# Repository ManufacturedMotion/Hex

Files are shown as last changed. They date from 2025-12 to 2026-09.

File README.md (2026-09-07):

# Hex

<a href="https://manufacturedmotion.github.io/Hex/">
  <button>Open Hex Documentation</button>
</a>

Hex is a six legged OpenSource Hexapod designed to serve as a moving platform for you to tinker with and build on top of! 

The current Hexapod release is **Hex3**. Check out our [Hex3 project on Printables!](https://www.printables.com/model/1831798-hex3-an-opensource-hexapod-platform) Hex4 is currently under development, with a target release date in mid- to late- 2027.

Like Tony Stark and his suits, we are continually expanding on the capabilities of the Hexapod platform. Unlike Tony Stark, we hope not to need
85+ different iterations.

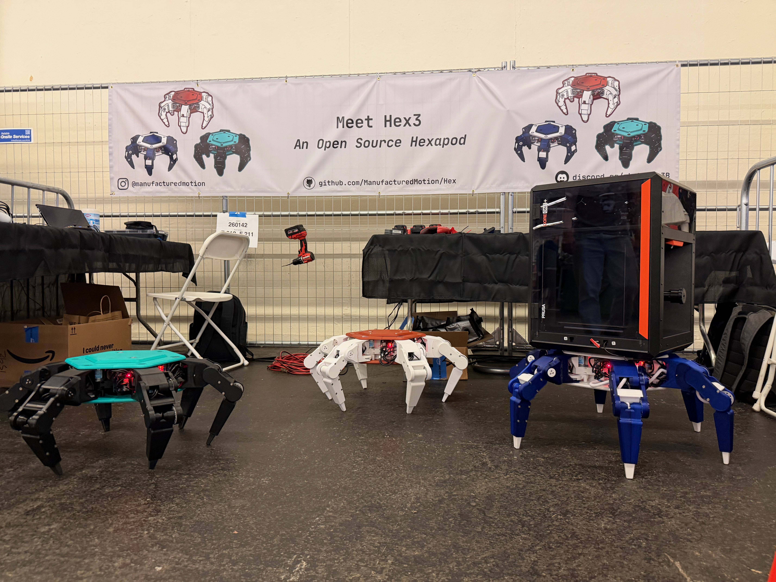
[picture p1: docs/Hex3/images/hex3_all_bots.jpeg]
Hex3 bots at OpenSauce


If you want to build your own or join the community, check out our [Hex Discord](https://discord.gg/v3bbvRtFUr).

To find out info on what we're planning to change, [checkout our GitHub issues!](https://github.com/ManufacturedMotion/Hexapod/issues).

## Generations

### Hex1

- [Overview](https://github.com/ManufacturedMotion/Hexapod/wiki#mk1)
- Completed: July 2023 - May 2024
- MIT LICENSE

### Hex2
- [Overview](https://github.com/ManufacturedMotion/Hexapod/wiki#mk2)
- Completed: May 2024 - July 2025
- MIT LICENSE

### Hex3
- Codename: Dewey
- In-Progress: July 2025 - September 2026
- Code: GNU GENERAL PUBLIC LICENSE V3
- CAD/PCBs: [Open Community License (OCL)](https://github.com/OpenCommunityLicence/OpenCommunityLicence?tab=readme-ov-file#open-community-license-ocl)
- Printables: [Hex3](https://www.printables.com/model/1831798-hex3-an-opensource-hexapod-platform)

### Hex4
- In-Progress: August 2026 - Present

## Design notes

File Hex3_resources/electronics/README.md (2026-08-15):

# Hex3 PCB Electronics

## Overview

This folder contains the Hex3 PCB resources, including the latest leg and main PCB revisions used for this project.

## Leg Board Versions

- `V2.0` - earlier leg board revision.
- `V3.2` - improved leg board revision.

(Both of these boards were used on the hexapods during OpenSauce 2026)

## Key Differences

- `V2.0`:
  - This board added some new features such as:
    - added split termination to our canbus circuit
      - NOTE: our testing showed this feature actually introduced issues. If using the V2.0 design, you will need to cut the traces to remove connection to the split termination circuit. [See our GitHub Pages for HEX3 PCB assembly for detailed instructions](../../docs/Hex3/pcb-assembly.md)
    - added a diode to prevent power issues when connecting to the Xiao via USB
    - 470uF capacitor to stabilize power supply to the Xiao RP2350
    - swaps the polarized DRV capacitors from SMT to through hole for easier assembly
      - for some reason, for the original V1.0 boards, we decided to solder the SMT capacitors by hand instead of having it done by a machine...
    - added TJA1050 chip as we swapped the communication protocol for main PCB <-> leg PCB from I2C to canbus
    - added LTC4311 chip to improve I2C transmission speed and reliability (I2C is still used for encoder reads)

- `V3.2`:
  - This board resolved a few design issues from V2.0, but also is more expensive as we swapped to 2 oz copper pours for all layers
  - Changes from V2.0 include:
    - removed split termination from the canbus circuit
    - added via stitching to the board for better heat dissipation
    - added an option to use header/pogo pins for the Xiao RP2350 connectivity 
    - silk screen changes to 0 index the encoder labels
    - swap the placements of the encoder JST connections, so that S0 is the closest to the top of the board
    - swap the through hole diode for an SMT version

> Please see the [Hex3 PCB assembly documentation](../../docs/Hex3/pcb-assembly.md) for additional notes about assembly and required code changes for either version of the leg board.

## Main Board Versions

- `V2.1`:
  - The main board is more stable than our leg boards, as V2.1 was the only version we used for OpenSauce 2026
  - Our only note is for the addition of a 470uF polarized capactior across the input terminals of one of the buck converters on the board. This is explained on the PCB assembly instructions linked above

## Ordering

PCBs were ordered from JLCPCB, but any PCB vendor that supports ASM should work. Both the main and leg PCBs are designed as 4 layer PCBs

> For convenience and as an example, the BOM and CPL files from our last order have been added only to the `leg_board/` folders.
>> Our order was a bulk order for 25 boards. If using these files as a reference, please adjust the quantities accordingly.

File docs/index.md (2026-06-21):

<p style="text-align:center">
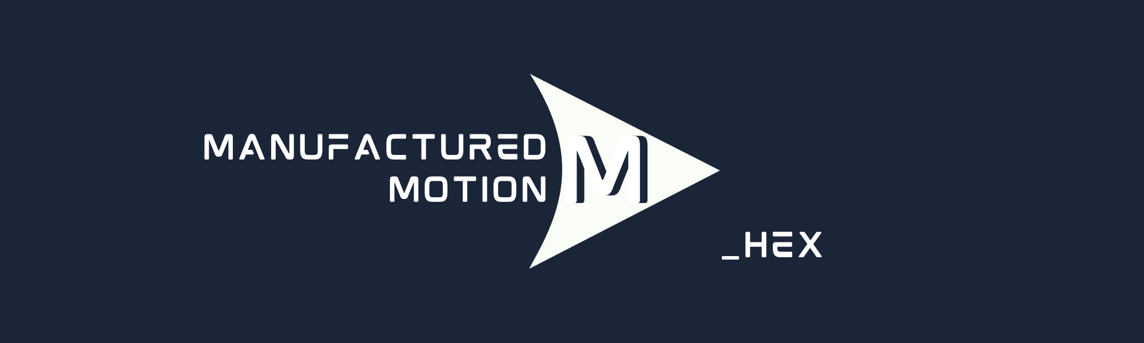
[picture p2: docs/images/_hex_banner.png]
Hex Banner
  
</p>

## What is Manufactured Motion?
Manufactured Motion is the combined efforts of three recent college graduates with a passion for robotics! You can find out more about our members in our [Meet the Team page](meet-the-team.md).

## What is a Hexapod?
Typically, in robotics, a hexapod refers to a motion control system that has six legs and 3 degrees of freedom both linearly and axially.

## Project History

In May of 2023 we set out to design a Hexapod which would primarily be 3D printed and maintain a relatively low cost to build. This OpenSource Hexapod has been designed to serve as a moving platform for you to tinker with and build on top of! We planned for this hexapod to be controlled with a wireless controller, have multiple options for maneuverability, and [stretch goal] utilize machine learning to track and follow objects. 

So far this project has seen three major design iterations, aptly named Hex1, Hex2, and Hex3. We had an amazing time sharing our Hex2 design at OpenSauce 2025, and we set out to create a far more capable Hexapod for Hex3!

- [Hex1](Hex1/index.md)
  - Completed: July 2023 - May 2024
- [Hex2](Hex2/index.md)
  - Completed: May 2024 - July 2025
- [Hex3](Hex3/index.md)
  - In-Progress: July 2025 - Present

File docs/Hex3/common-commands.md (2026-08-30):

# Common Commands

!!! note
    The following are useful commands to have handy when experimenting with or debugging your hexapod.

## Docker Containers
The following are commands used to setup or run a docker container for our environment. They would be run from inside the `non_real_time/container/` directory on your pi

* `./init_dev.sh`
  * initialize the docker container environment
* `./new_dev_shell.sh`
  *  opens a new shell in the container

## ROS2 Packages & Nodes
These commands are expected to be run inside of a development container (see above)

Hex3 drives its legs over CAN instead of a Teensy over serial. Joystick input flows through `control` into `tripod_gait`, which is turned into per-leg targets by `inverse_kinematics`, and finally dispatched to the motors by the `can` package.

* `ros2 launch hexapod_manager hexapod.launch.py`
  * launches the full walking stack in one shot: `control`, `joy`, `inverse_kinematics`, `can_interface`, and `tripod_gait`. This is the standard way to bring the hexapod up for xbox-controlled walking and requires the xbox controller to be on and connected to the pi via bluetooth before being run.
* `ros2 launch control xbox.yml`
  * launches just the joy and xbox controller config nodes used for communicating button/stick input as `/cmd_vel` and `/macros`. Useful when you only need controller input without the rest of the walking stack (e.g. when pairing with `led_controller` below). This launch also requires the xbox controller to be on and connected to the pi via bluetooth before being run.
* `ros2 run hexapod_manager led_controller`
  * launches a node responsible for controlling the led ring on the bottom of the hexapod. Can be used alongside `xbox.yml` or `hexapod.launch.py` to give color and pattern toggling capabilities. 
* `ros2 run hexapod_tester hexapod_tester`
  * launches a diagnostic node that sweeps the body pose and foot targets through a repeating pattern on `/body_pose` and `/foot_targets`, useful for exercising `inverse_kinematics` and the CAN link without a controller attached. Pair it with `ros2 launch hexapod_manager hexapod.launch.py` running in another shell.
* `ros2 topic echo <topic>` 
  * listens in to the specified topic. Useful options include `/joy`, `/cmd_vel`, `/macros`, `/body_pose`, `/foot_target`, and `/leg_commands`

## CAN

!!! note
    These commands should not be needed during normal operation of the Hexapod as there is a service to bring CAN up and down automatically, but they may be useful during debugging.

    These commands should be run in the Pi terminal, not in the docker container.

* Bring CAN down

```bash
sudo ip link set can0 down
```

* Set CAN bitrate

```bash
sudo ip link set can0 type can bitrate 500000
```

* Bring CAN up

```bash
sudo ip link set can0 up
```

* Monitor CAN

```bash
candump can0
```

* Send a dummy message

```bash
cansend can0 123#DEADBEEF
```

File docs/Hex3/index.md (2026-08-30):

# Hex 3

Hex3 All Bots

## Overview

Hex3 is the third generation of our Hexapod platform. Highlights of this generation:

- 10kg (~22lb) payload capacity
- Drivable via Xbox controller
- Fully 3D printed body and legs
- 18 degrees-of-freedom (DOF) design with 3 DOF per leg
- Custom low-cost servos made using DC gear motors and AS5600 magnetic encoders (as opposed to the hobby-servos that were prone to overheating on [Hex2](../Hex2/index.md).)
- Spring loaded toe with position sensor to measure force applied by each leg
- Three-level control to follow user commands
    - High level whole hexapod gait
    - Model predictive control enabling each leg to apply a directionally controlled force of a specified magnitude
    - Each axis controlled using PID with feedforward control based on current loads and requested accelerations for accurate path following
- Custom PCBs for Pi and leg connectivity
- Standard hardware holding the Hexapod together
- Modular compute architecture 
- Deterministic real time compute provided by Xiao RP2350s
- ROS2 on Raspberry Pi 5 to allow easy build in to existing robotic development platforms

Price point: ~$2,000 USD. 

!!! note
    The Hex3 platform is not being actively developed against, and is instead considered "steady-state" for a release. If you have modifications or features you would like to add, please either make a PR and request a review in our [Hex Discord](https://discord.gg/v3bbvRtFUr), or publish a fork of this project. 

/// html | div.grid

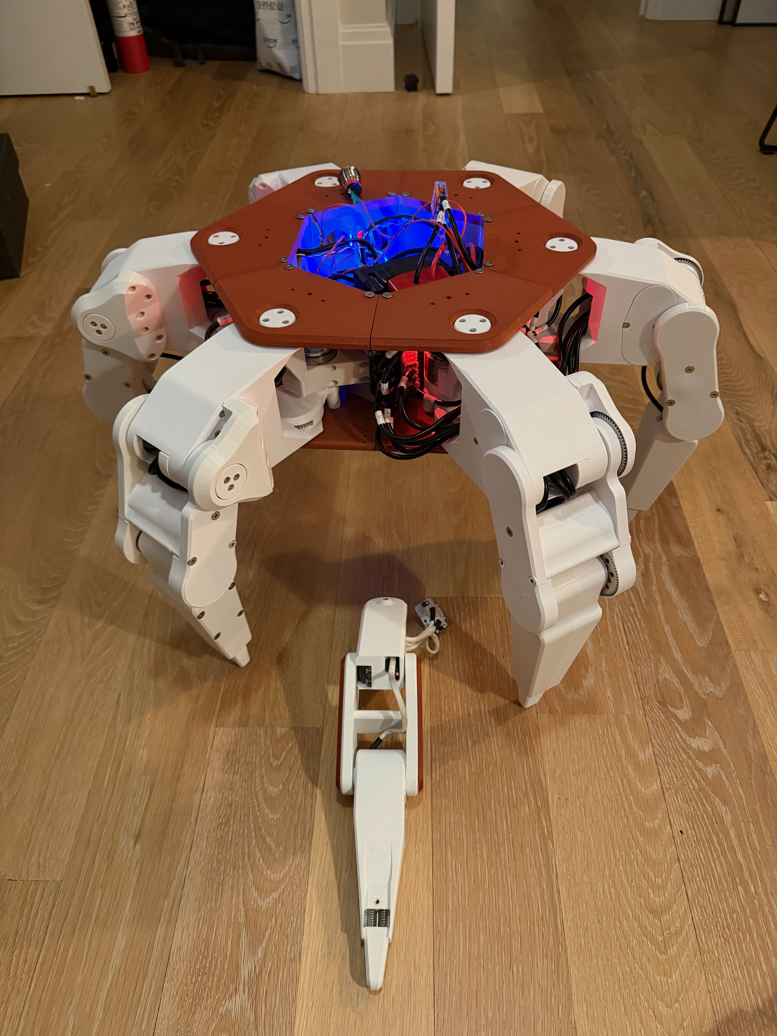
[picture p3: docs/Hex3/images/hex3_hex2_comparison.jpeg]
Hex3 Hex2 Comparison Bots


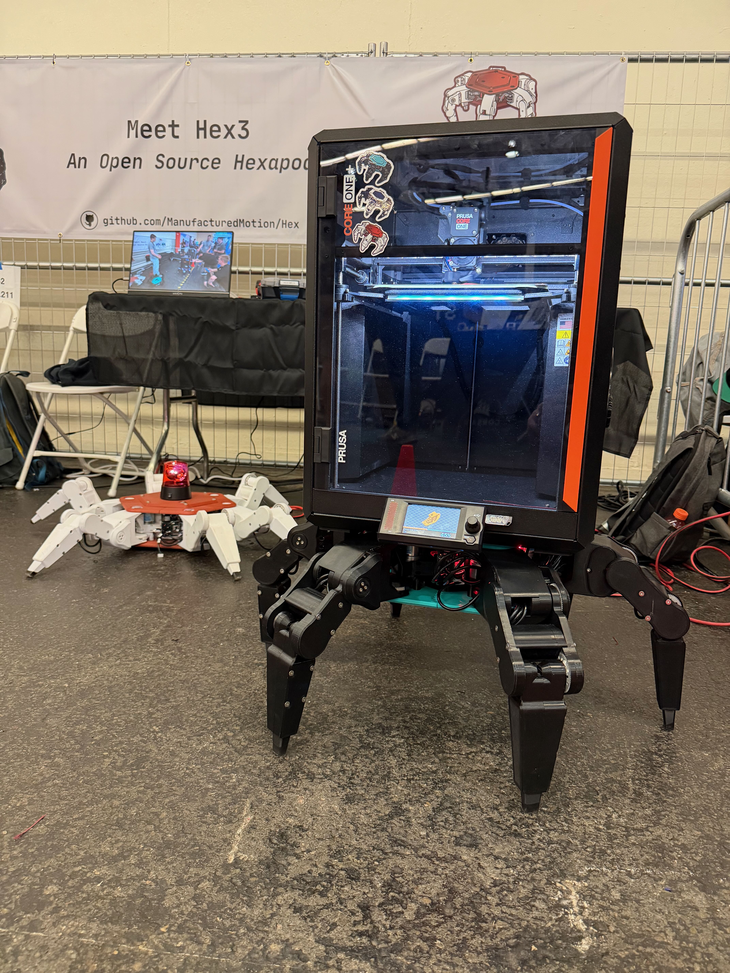
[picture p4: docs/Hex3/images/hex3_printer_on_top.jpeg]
Hex3 Printer on Top


///

---

## Software Stack

Command and control still runs on a Raspberry Pi 5, but each leg now carries its own [Seeed Xiao RP2350](https://www.seeedstudio.com/Seeed-Studio-XIAO-RP2350-p-5944.html) microcontroller instead of a single central Teensy. The Pi talks to all six leg controllers over a shared CAN bus, so each leg handles its own axis control, encoder feedback, and toe (foot contact) sensing locally, then reports state back over CAN.

Hex3 runs ROS2 inside a Docker container on the Pi. Xbox controller input flows through a small pipeline of nodes:

`control` (xbox input) &rarr; `tripod_gait` &rarr; `inverse_kinematics` &rarr; `can` (dispatches to each leg's Xiao over CAN).

See the [Common Commands](common-commands.md) page for how to launch this stack and the individual nodes, and the [Raspberry Pi Setup](raspberry-pi.md) page for configuring the Pi itself.

Each leg's real-time control loop (motor PID, encoder reads, toe sensing, and CAN messaging) runs as firmware on that leg's Xiao RP2350 — see [Real-Time Firmware](firmware-setup.md) for building, flashing, and calibrating it, and [Electronics Setup](electronics-setup.md) for wiring.

Fully 3D printed body and legs — see [3D Printing](3d-printing.md) for print recommendations.

---

## Project Glossary

- [Bill of Materials](https://docs.google.com/spreadsheets/d/1jHR1j3dNIgRCcadYxqtaftRhhn8tEC1XY8og_EQwXEU/edit?gid=0#gid=0)
- [CAD Models](https://github.com/ManufacturedMotion/Hex/tree/main/Hex3_resources/cad)
- [Electronics](https://github.com/ManufacturedMotion/Hex/tree/main/Hex3_resources/electronics)
- [Raspberry Pi / ROS2 Code](https://github.com/ManufacturedMotion/Hex3/tree/main/non_real_time)
- [Real-Time (Xiao) Firmware](https://github.com/ManufacturedMotion/Hex3/tree/main/real_time)

---

## Potential Improvements

The following items are not planned prior to the release of Hex3, but would likely be beneficial for someone to tackle in the future:

### CAD
- S1 to have replaceable magnet holder (similar to S2/S3)
    - Make the entire hexapod a few mm taller to account for this
- S0 gear cover prevent breakage
- Redesign S3 to allow for toe replacement without needing to fully disassemble S2 + S3
- S1 gear cover thicker to allow for M18 screws
- Increase S2 thickness to allow for more S3 motor pinout clearance
- Beef up S2 due to consistent breaking

### Non-Real Time Code
- Vibrate the controller on low battery
- Remove outdated/unnecessary code
- Add in additional macros

### Real Time Code
- Configure toe ToF sensors + integrate them into walking gaits
- Dynamic gait adjustment based on payload

### Main PCB
- Switch over to more powerful Buck Converter, instead of two smaller buck converters (liklely [this buck converter](https://www.digikey.com/en/products/detail/tdk-lambda/I3A4W005A150V-001-R/7321112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))
- Capacitors on input to Buck Converter

--- 

## License

[GNU General Public License v3.0](https://github.com/ManufacturedMotion/Hex3/blob/main/LICENSE)

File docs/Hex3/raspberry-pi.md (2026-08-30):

# Raspberry Pi Setup

This section will walk you through configuring the Raspberry Pi 5 with Raspberry Pi OS, Docker, and ROS2. 

## Requirements
- Raspberry Pi 5
- Micro SD Card (64GB+ preferred).
- Micro HDMI to HDMI cable.
- USB connected keyboard.
- USB connected mouse.

---

## Flash the SD Card

1. [Download the Raspberry Pi imager](https://www.raspberrypi.com/software/)
1. Select `Raspberry Pi 5` as the board
1. Select `Raspberry Pi OS (64-bit)`
1. Select your micro SD card.
1. Select your configuration settings. Recommended settings include:
    - Host Name: hexapod-<last_name>
    - User: hexapod<last_name>
    - Enable SSH via authentication.
1. Click save + wait.
1. Once flashed, plug your micro SD card into your Pi and connect peripherals.

## Install Docker

1. Update the system:
    ```bash
    sudo apt update && sudo apt full-upgrade -y
    ```

1. Download the Docker install script:
   ```bash
   curl -fsSL https://get.docker.com -o get-docker.sh
   ```

1. Install Docker:
   ```bash
   sudo sh get-docker.sh
   ```

1. Add your user to the `docker` group:
   ```bash
   sudo usermod -aG docker $USER
   ```

1. Log out and back in (or reboot) for the group change to take effect:
   ```bash
   sudo reboot
   ```

1. Verify the installation:
   ```bash
   docker --version
   docker compose version
   docker run hello-world
   ```

## Add the Necessary Config Overrides

1. Access the config file:

    ```bash
    sudo nano /boot/firmware/config.txt
    ```

1. Add the following lines to the end of the file:

    ```bash
    dtparam=spi=on
    dtoverlay=mcp2515-can0,oscillator=16000000,interrupt=25 
    ```

## Automatically Launch CAN at Startup

1. Install `can-utils`, which provides the `ip link ... type can` support used below, along with `candump`/`cansend` for debugging:
    ```bash
    sudo apt install can-utils
    ```

1. Get the path to `ip`:
    ```bash
    which ip
    ```

    ```
    /usr/sbin/ip
    ```

1. Create the file `/etc/systemd/system/canbus.service` with the following contents, using the path from the step above:
```bash
    [Unit]
    Description=CAN Bus Interface

    [Service]
    ExecStart=/usr/sbin/ip link set can0 up type can bitrate 500000
    Type=oneshot
    RemainAfterExit=yes

    [Install]
    WantedBy=multi-user.target
```

1. Bring the service up:

    ```bash
    sudo systemctl start canbus.service
    ```

## Connect Xbox Core (Series S, X, etc) Controller

1. Connect the controller via Raspberry Pi OS's Bluetooth UI or via terminal.

## Update Docker User Config

1. Navigate to `non_real_time/container/src/ros2_ws/src/hexapod_manager/config/robot_name.local.txt`.
1. Add your Hexapod name to `robot_name.local.txt`. This should be the only text in the file.
1. Make sure the robot name is in `non_real_time/container/src/ros2_ws/src/hexapod_manager/launch/hexapod.launch.py` with a unique ROS_DOMAIN_ID.
1. Trigger a build:
    1. Initialize the dev container:

        ```bash
        ./init_dev.sh
        ```

    1. Get a new shell:

        ```bash
        ./new_dev_shell.sh
        ```

    1. Build the ROS2 Nodes

        ```bash
        colcon build
        ```

    1. Next time you restart the pi, the changes will take effect. To test you can also run:

        ```bash
        docker compose -f docker-compose-prod.yml up
        ```

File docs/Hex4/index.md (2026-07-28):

# Hex 4

!!! Note
    Any files within the Hex4/ repo, or documents contained in this section, are currently a work in progress. The current Hexapod release is **Hex3**. Hex4 is currently under development, with a target release date in mid- to late- 2027.

Like Tony Stark and his suits, we are continually expanding on the capabilities of the Hexapod platform. Unlike Tony Stark, we hope not to need
85+ different iterations.

More details are coming soon, but the next generation of the Hexapod platform (Hex4) is targeting a much higher **continuous** payload capacity rivaling Hex3's momentary payload capacity.

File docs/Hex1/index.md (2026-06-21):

# Hex1

!!! warning "Hex1 Deprecated"
    Hex1 is deprecated as of August 2024.

    The files for Hex1 are still available, but may be incomplete due to the project pivot.

    We strongly recommend building the current Hex2/Hex3+ design instead, as Hex1 has known hardware and software limitations.

    All aspects of the system are being improved in later versions, including printed parts and electronics.

---

## Overview

This version of the Hexapod was completed in Summer 2024. It came in under the $500 budget and used a Raspberry Pi Zero W and Teensy 4.1 for control.

While Hex1 was a successful proof of concept (Bluetooth control, basic gait, etc.), it quickly became clear that both hardware and software would limit future development.

Because of this, development moved toward Hex2 and beyond.

---

## CAD Model

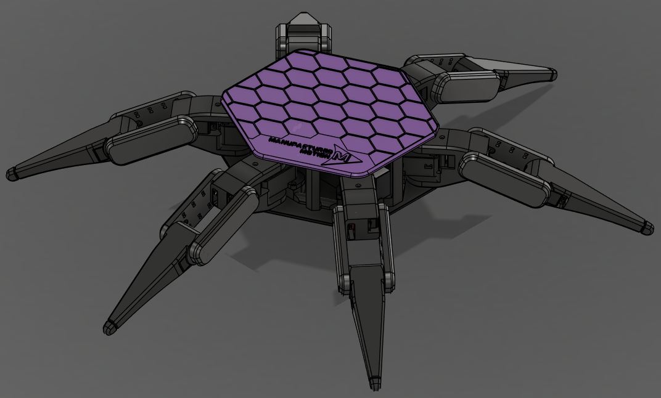
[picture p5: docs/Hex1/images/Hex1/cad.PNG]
Hex1 CAD


---

## Electronics

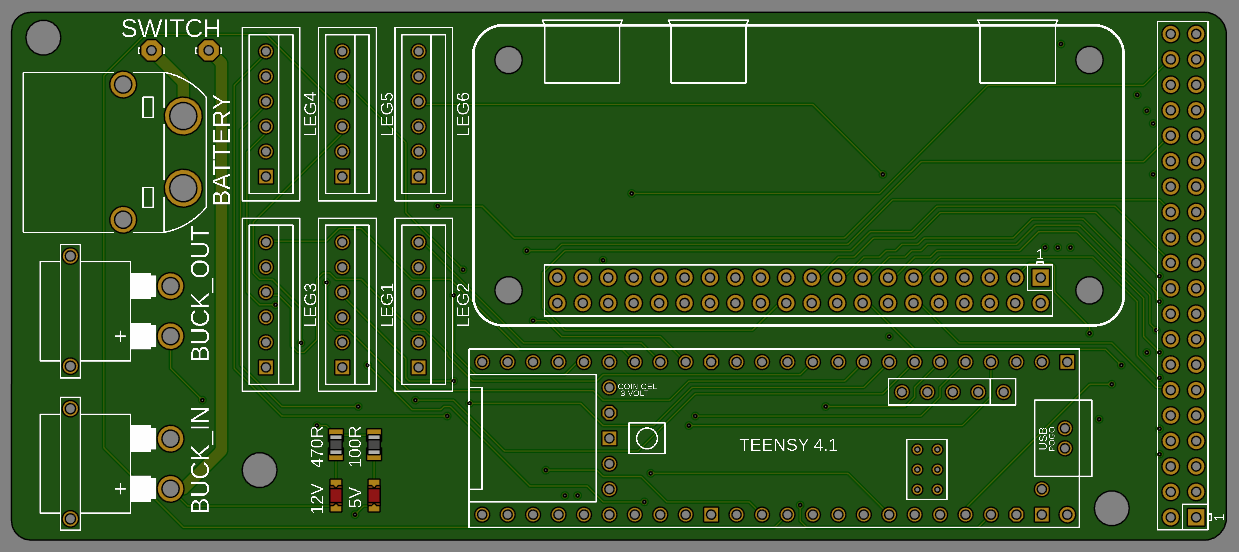
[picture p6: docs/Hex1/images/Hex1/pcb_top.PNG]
Hex1 PCB Top


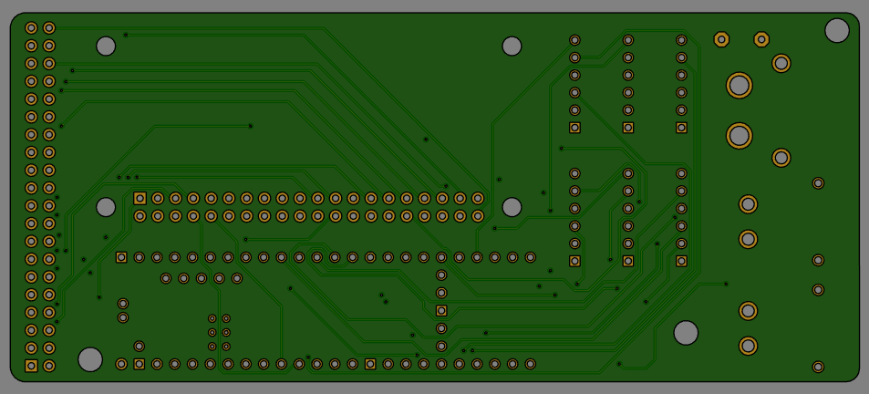
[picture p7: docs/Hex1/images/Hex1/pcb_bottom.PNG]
Hex1 PCB Bottom


---

## Hex1 Project Glossary

- [3D Models](https://github.com/ManufacturedMotion/Hexapod/tree/main/Hex1_resources/CAD)
- [Bill of Materials](https://github.com/ManufacturedMotion/Hexapod/tree/main/Hex1_resources/BOM)
- [Teensy Code](https://github.com/ManufacturedMotion/Hex1/tree/main/real_time)
- [Raspberry Pi Zero Code](https://github.com/ManufacturedMotion/Hex1/tree/main/non_real_time)
- [Electronics](https://github.com/ManufacturedMotion/Hexapod/tree/main/Hex1_resources/electronics)

---

## License

MIT LICENSE

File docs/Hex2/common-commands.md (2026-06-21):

!!! note
    The following are useful commands to have handy when experimenting with or debugging your hexapod.

## Docker Containers
The following are commands used to setup or run a docker container for our environment. They would be run from inside the `mk2/code/non_real_time/container/` directory on your pi

* `./init_dev.sh`
  * initialize the docker container environment
* `./new_dev_shell.sh`
  *  opens a new shell in the container

## Ros2 Packages & Nodes
These commands are expected to be run inside of a development container (see above)

Here is an rqt graph showcasing the relationship of our custom nodes

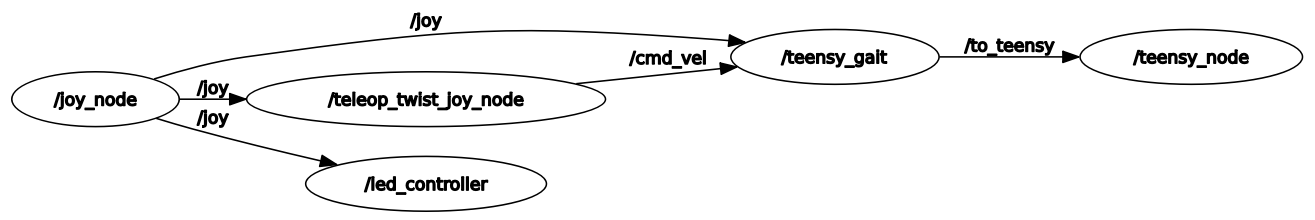
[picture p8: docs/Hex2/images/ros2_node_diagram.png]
ROS2 RQT Graph


* `ros2 launch control xbox.yml`
  * launches the joy and cmd_vel nodes used for communicating with the pi via xbox controller. This launch requires the xbox controller to be on and connected to the pi via bluetooth before being run.
* `ros2 run teensy_node teensy_node`
  * launches a node responsible for pi <-> teensy serial communication.
* `ros2 run gait teensy_gait`
  * launches a node that allows the hexapod to be remote controlled with the xbox controller. Operation requires that you have also launched xbox.yml.
* `ros2 run hexapod_manager led_controller`
  * launches a node responsible for controlling the led ring on the bottom of the hexapod. Can be used alongside xbox.yml to give color and mode toggling capabilities. 
* `ros2 topic echo <topic>` 
  * listens in to the specified topic. available options are `/from_teensy`, `/to_teensy`
* `ros2 launch hexapod_manager user_controlled.yml`
  * launches the controller, leds, and teensy nodes needed for wireless walking control

## Serial Commands
When LOG_LEVEL is set to a value greater than 1 in user_config.hpp, the user is able to send instructions to the teensy via serial. The command formats are as follows:

### Presets
* `{"PRE": "Z"}`
  * The hexapod will move all motors to their zero positions
* `{"PRE": "SIT"}`
  * The hexapod will sit down
* `{"PRE": "STND"}`
  * The hexapod will stand up

### Movement Instructions
* The hexapod will execute the `hexapod.rapidMove` function to move to the specified position:

```bash
{"MV": "RPD", "X": <x>, "Y": <y>, "Z": <z>, "ROLL": <roll>, "PTCH": <pitch>, "YAW": <yaw>}
```

* The hexapod will execute the `hexapod.walkSetup` function to move to the specified position at the specified speed:

```bash
{"MV": "WLK", "X": <x>, "Y": <y>, "Z": <z>, "ROLL": <roll>, "PTCH": <pitch>, "YAW": <yaw>, "SPD": <speed>}
```

* MTPS is used to set all 18 motors to a specified position, in this example all motors go to pos 0. Not all motors must be specified, but it is desired. If any motor is not specified in the command, it will may or may not move. Movement will be dependent on a local variable inside of our JSON parsing code. Unspecified motors will always try to move to the last stored position:

```bash
{"MV":"MTPS", "L0S1":0,"L0S2":0,"L0S3":0,"L1S1":0,"L1S2":0,"L1S3":0,"L2S1":0,"L2S2":0,"L2S3":0,"L3S1":0,"L3S2":0,"L3S3":0,"L4S1":0,"L4S2":0,"L4S3":0,"L5S1":0,"L5S2":0,"L5S3":0}
```

* TUNE is used to tune a specific motor's position. The hexapod executes `heaxpod.moveLegAxisToPos`:

```bash
{"MV":"TUNE", "L<leg>S<axis>": <pos>}
```

* The hexapod will execute the `hexapod.legEnqueue` function to add a 3 by 1 movement command to the instruction queue.

```bash
{"MV": "3B1", "X": <x>, "Y": <y>, "Z": <z>, "ROLL": <roll>, "PTCH": <pitch>, "YAW": <yaw>, "TIME": <move time>}
```

* The hexapod will execute the `hexapod.linearMoveSetup` function to move to the specified position at the specified speed.

```bash
{"MV": "LMS", "X": <x>, "Y": <y>, "Z": <z>, "ROLL": <roll>, "PTCH": <pitch>, "YAW": <yaw>, "SPD": <speed>}
```

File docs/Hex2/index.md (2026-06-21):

!!! warning "Hex2 Deprecated"
    Hex2 was deprecated in July 2025. While the Manufactured Motion repositories still contain all materials needed to build and control Hex2, it is no longer actively supported. You are welcome to fork the repository to continue development.

    Hex2 lacks many of the quality-of-life improvements and features introduced in Hex3. The two main limitations are:

    - Hobby-grade servos can overheat, limiting continuous runtime to only a few minutes.
    - Maximum payload is only a few pounds, compared to the 50+ pound target for Hex3.

## Overview

This second iteration of the Hexapod design utilizes a Raspberry Pi 5 and Teensy 4.1 for command and control.

Hex2 also introduces a redesigned PCB with key improvements, including separate voltage rails for direct servo power delivery.

A full CAD overhaul was performed to reduce part count and improve modularity, allowing components to be swapped without reprinting large assemblies.

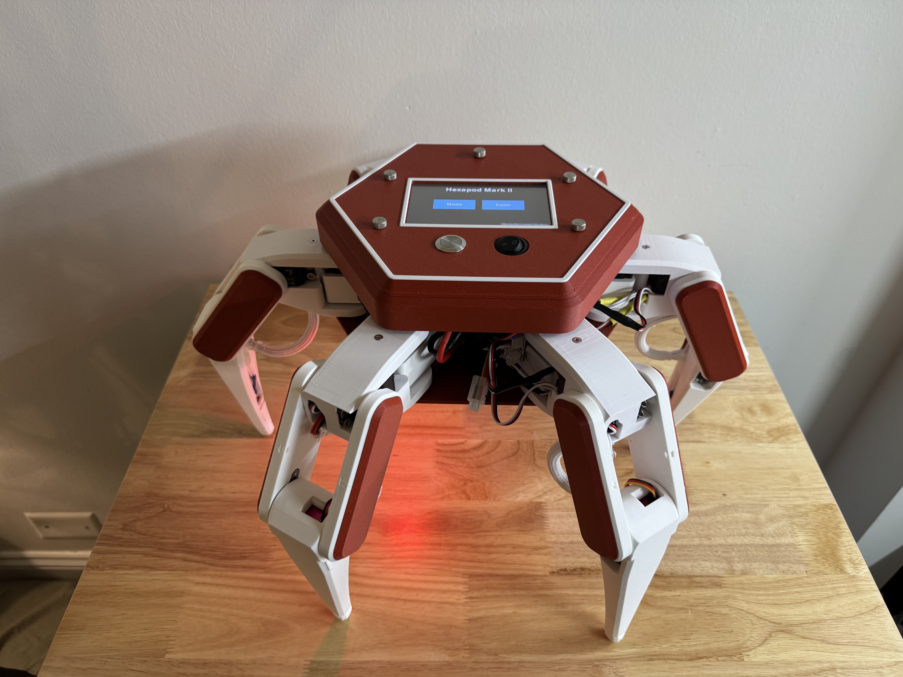
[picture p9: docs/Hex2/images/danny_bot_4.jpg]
Hex2 Bot 1

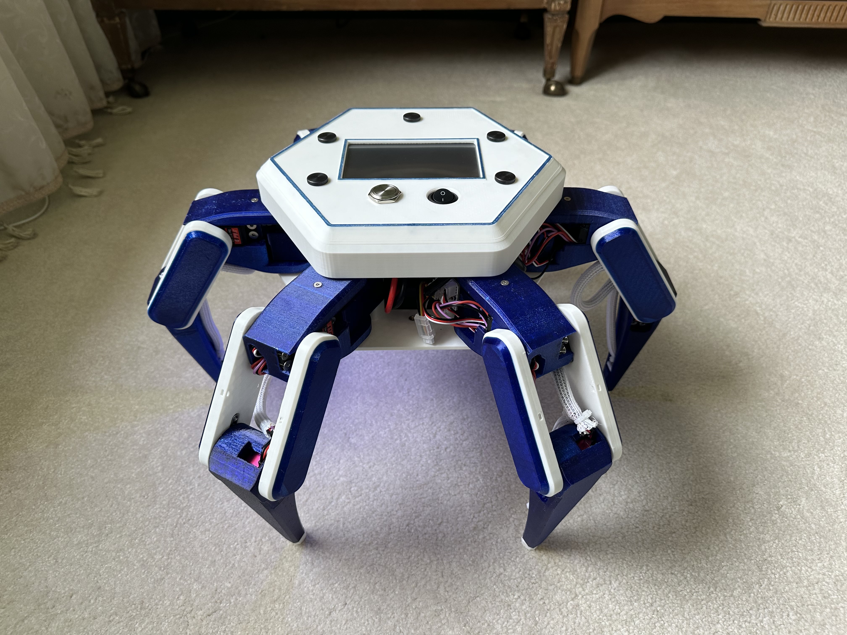
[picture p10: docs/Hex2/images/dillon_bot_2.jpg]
Hex2 Bot 2

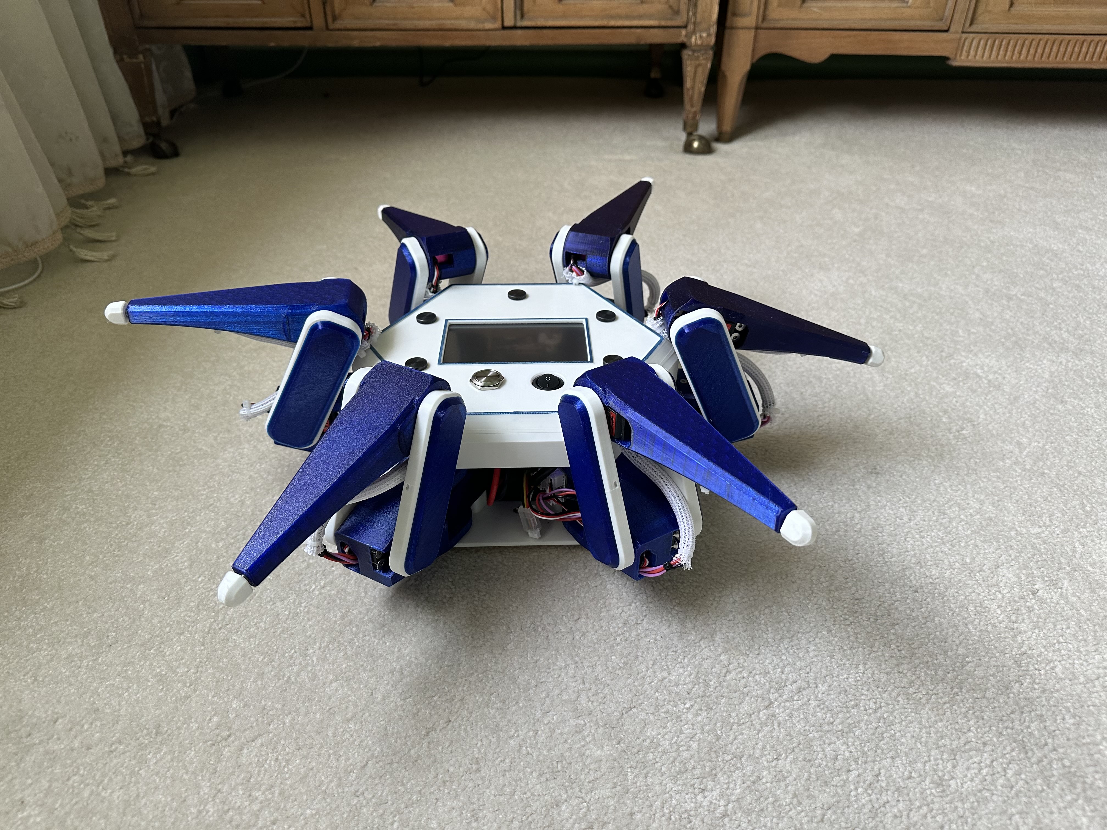
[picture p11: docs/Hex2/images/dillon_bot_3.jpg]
Hex2 Bot 3


---

## Software Stack

Hex2 transitions to ROS2 on Ubuntu, enabling integration with existing robotics ecosystems such as `joy` and `cmd_vel`, while also supporting custom nodes.

More details on launching ROS2 packages can be found in the Useful Commands section of the wiki.

A key example is the custom Teensy gait node, which parses controller input and sends movement instructions to the Teensy 4.1 in real time.

---

## CAD Model

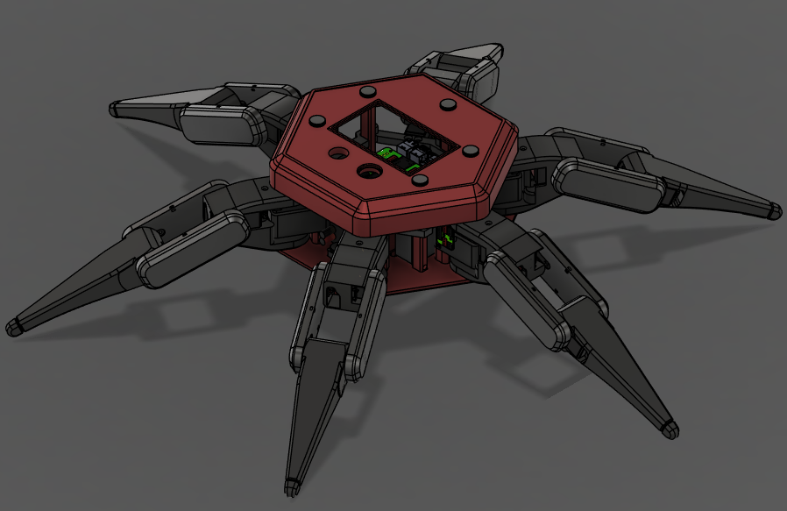
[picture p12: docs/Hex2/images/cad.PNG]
Hex2 CAD


---

## Electronics

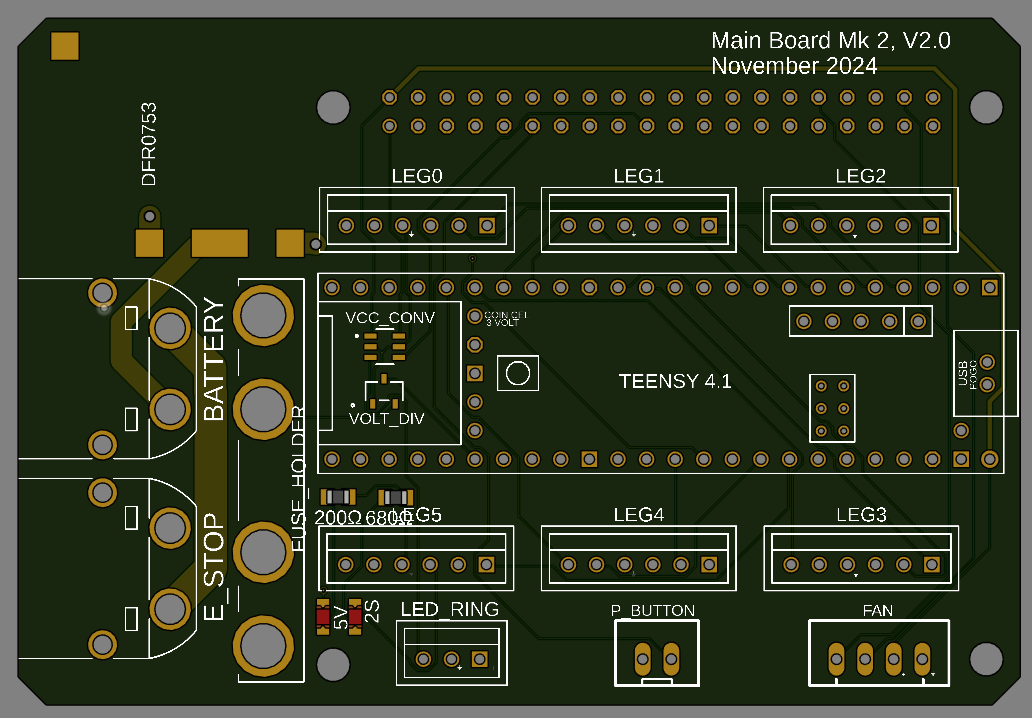
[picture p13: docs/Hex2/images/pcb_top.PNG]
Hex2 PCB Top

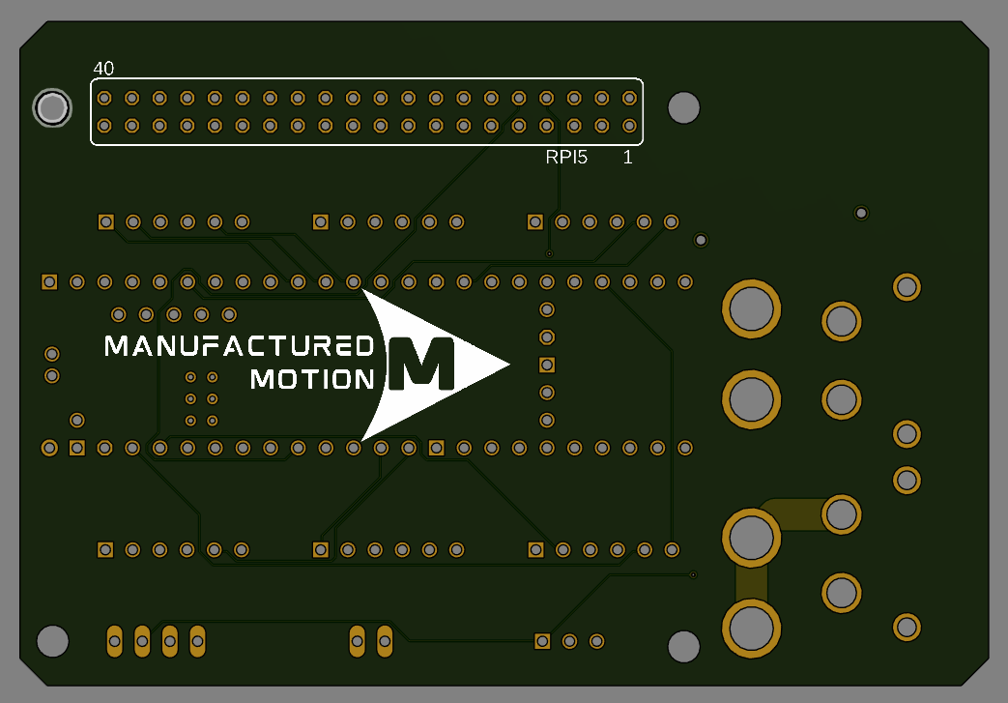
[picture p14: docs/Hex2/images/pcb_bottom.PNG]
Hex2 PCB Bottom


---

## Hex2 Project Glossary

- [3D Models](https://github.com/ManufacturedMotion/Hexapod/tree/main/Hex2_resources/CAD)
- [Bill of Materials](https://github.com/ManufacturedMotion/Hexapod/tree/main/Hex2_resources/BOM)
- [Teensy Code](https://github.com/ManufacturedMotion/Hexapod/tree/main/Hex2/real_time)
- [Raspberry Pi Code](https://github.com/ManufacturedMotion/Hexapod/tree/main/Hex2/non_real_time)
- [Electronics](https://github.com/ManufacturedMotion/Hexapod/tree/main/Hex2_resources/electronics)

---

## License

MIT LICENSE

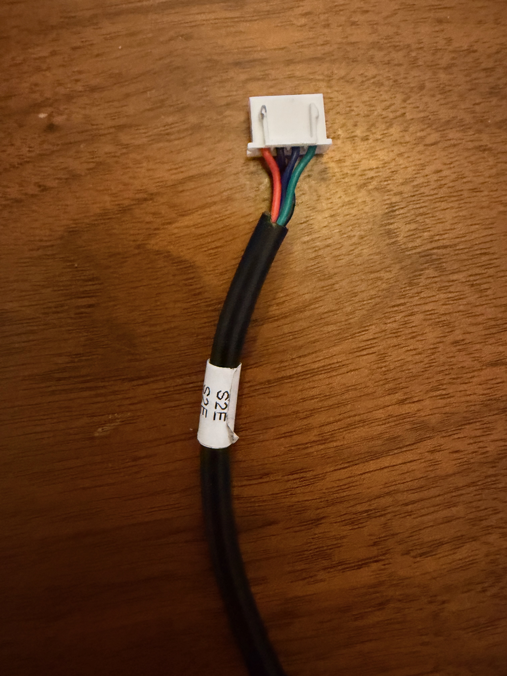
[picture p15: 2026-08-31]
site/Hex3/images/encoder_JST_pinout.jpeg

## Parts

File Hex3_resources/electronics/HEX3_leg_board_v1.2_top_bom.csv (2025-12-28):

Comment | Designator | Footprint | LCSC Part #
0.1uF/50V | C1 C3 C5 C7 | 0805-NO
1.2K | R2 | RESC2012X65
1.5K | R1 | RESC2012X65
1uF | C9 C10 | 0805-NO
10K | R4 R5 R6 R11 | RESC2012X65
10uF | C12 | 0805-NO
22K | R7 R8 R9 R10 | RESC2012X65
62K | R3 | RESC2012X65
DRV8871 | U1 U2 U3 U4 | HSOP8
LED_BLUE | VCC | LEDC2012X110N_FLAT-B
LED_RED | FUSE | LEDC2012X110N_FLAT-R
NCP718ASN500T1GTSOT23-5_ONS | U5 | TSOT23-5_ONS
TCA9548APWR | U6 | SOP65P640X120-24N
XIAO-RP2350-SMD | U$2 | XIAO-RP2350-SMD

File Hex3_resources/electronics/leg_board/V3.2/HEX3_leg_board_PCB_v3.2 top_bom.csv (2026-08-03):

Comment | Designator | Footprint | LCSC Part #
0.1uF | C13 | 0805-NO
0.01uF | C14 | 0805-NO
0.1uF/50V | C1 C3 C5 C7 | 0805-NO
1.5K | R1 | RESC2012X65
1uF | C9 C10 | 0805-NO
10K | R4 R5 R6 R11 | RESC2012X65
10uF | C12 | 0805-NO
22K | R7 R8 R9 R10 | RESC2012X65
62K | R3 | RESC2012X65
470 | R2 | RESC2012X65
DRV8871 | U1 U2 U3 U4 | HSOP8
LED_BLUE | VCC | LEDC2012X110N_FLAT-B
LED_RED | FUSE | LEDC2012X110N_FLAT-R
LTC4311_SC70 | IC1 | SC70-6L
NCP718ASN500T1GTSOT23-5_ONS | U5 | TSOT23-5_ONS
TCA9548APWR | U6 | SOP65P640X120-24N
TJA1050 | U8 | SOT96-1
ZENER | D2 | SODFL3718X115

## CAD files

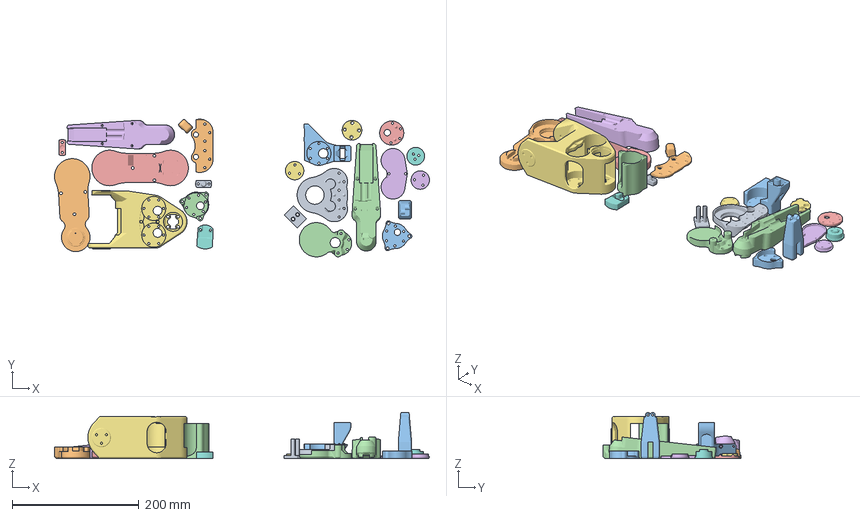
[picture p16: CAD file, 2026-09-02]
Hex3_resources/cad/release_3mfs/full_leg.3mf
590.6 x 217.0 x 72.5 mm
spring_aligner
toe tip
toe
s3_bearing_side
s3_magnet_mount
s3_gear_side
s3_gear_mount
s2_bearing_screw_mount
s2_magnet_mount
s2_gear_side
s2_connector_short
s2_connector_long
s2_bearing_side
s1_motor_cover
s1_bearing_holder_x2 x 2
s1_encoder_cover
s1_motor_bearing_mount
s1_motor_bearing_holder
s0
s0_gear_cover
s0_gear_cover_spacer
s1

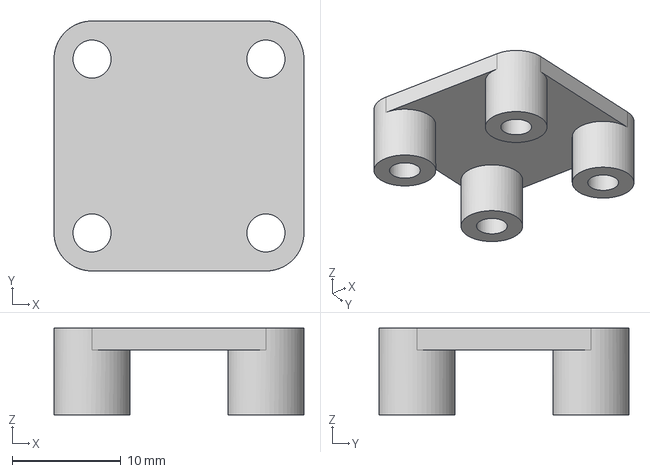
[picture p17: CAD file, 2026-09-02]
Hex3_resources/cad/encoder_insertion_tool.step
23.0 x 23.0 x 8.00 mm

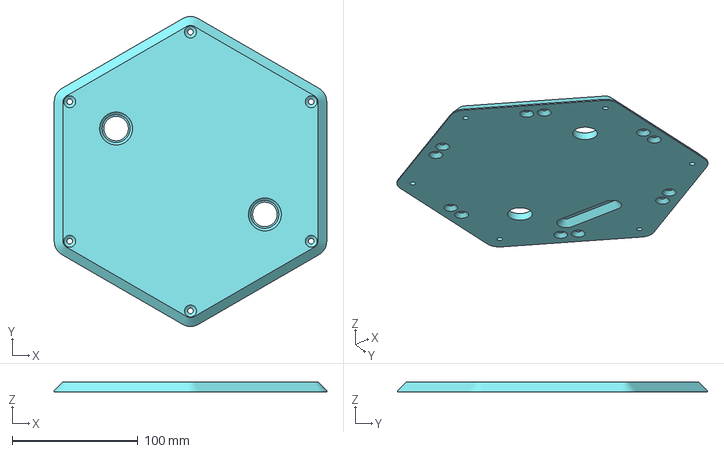
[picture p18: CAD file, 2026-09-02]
Hex3_resources/cad/release_3mfs/base_individuals/base_upper.3mf
216.5 x 246.2 x 8.00 mm

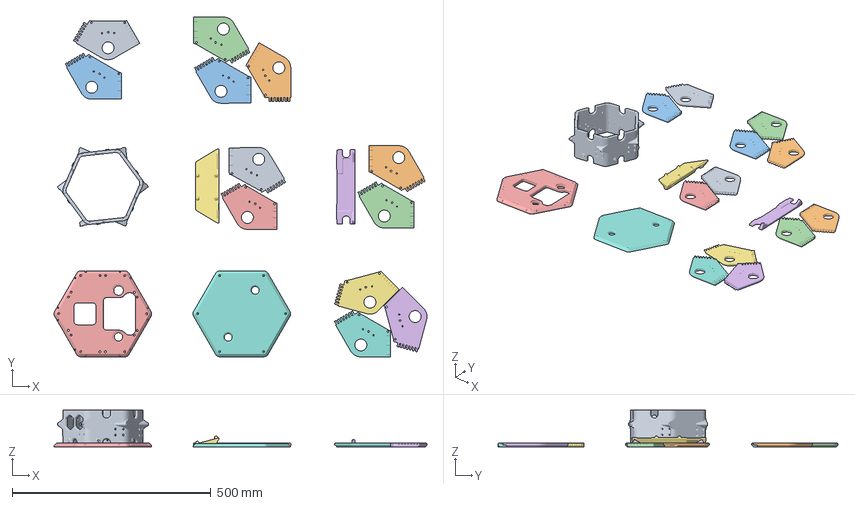
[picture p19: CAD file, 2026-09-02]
Hex3_resources/cad/release_3mfs/base_parts.3mf
939.4 x 855.8 x 92.0 mm
base_flat
base_lower
base_pcb_guard
base_electronics_mount
base_upper
base_core

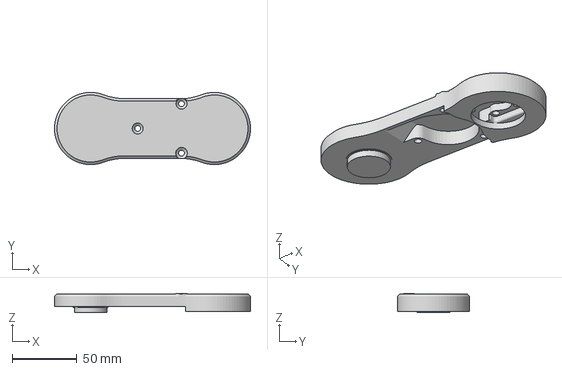
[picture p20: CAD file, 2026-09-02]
Hex3_resources/cad/release_3mfs/leg_individuals/s2_bearing_side.3mf
152.0 x 56.0 x 14.8 mm

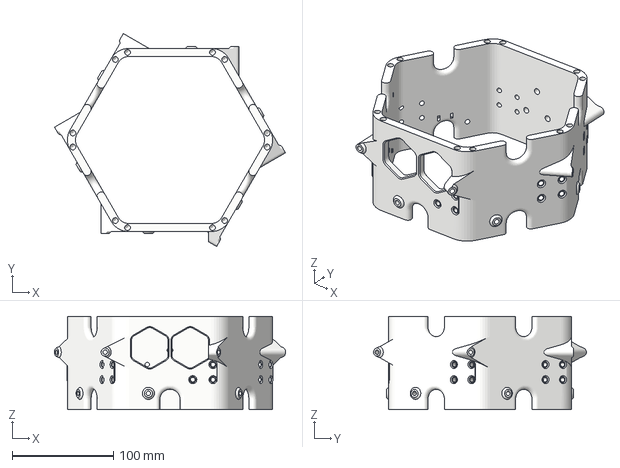
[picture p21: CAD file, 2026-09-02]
Hex3_resources/cad/release_3mfs/base_individuals/base_core.3mf
228.2 x 210.3 x 92.0 mm

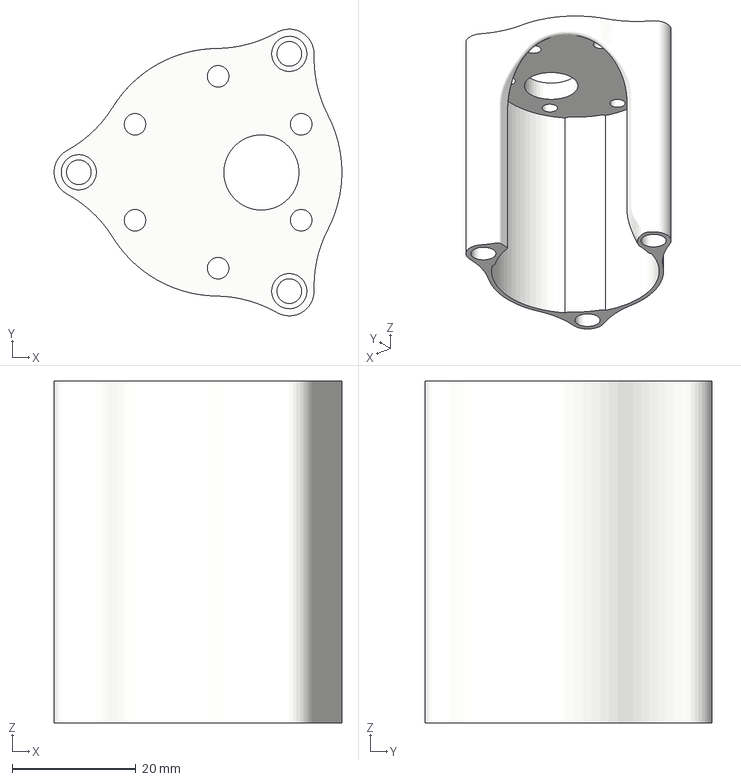
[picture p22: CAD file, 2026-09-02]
Hex3_resources/cad/release_3mfs/leg_individuals/s2_connector_long.3mf
46.5 x 46.3 x 55.3 mm

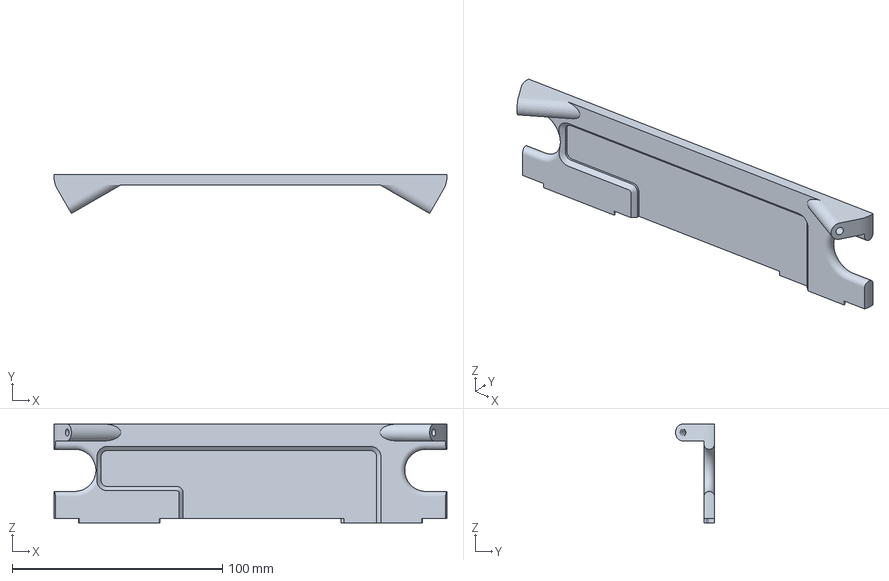
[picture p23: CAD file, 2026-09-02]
Hex3_resources/cad/release_3mfs/base_individuals/base_pcb_guard.3mf
186.8 x 18.5 x 47.0 mm

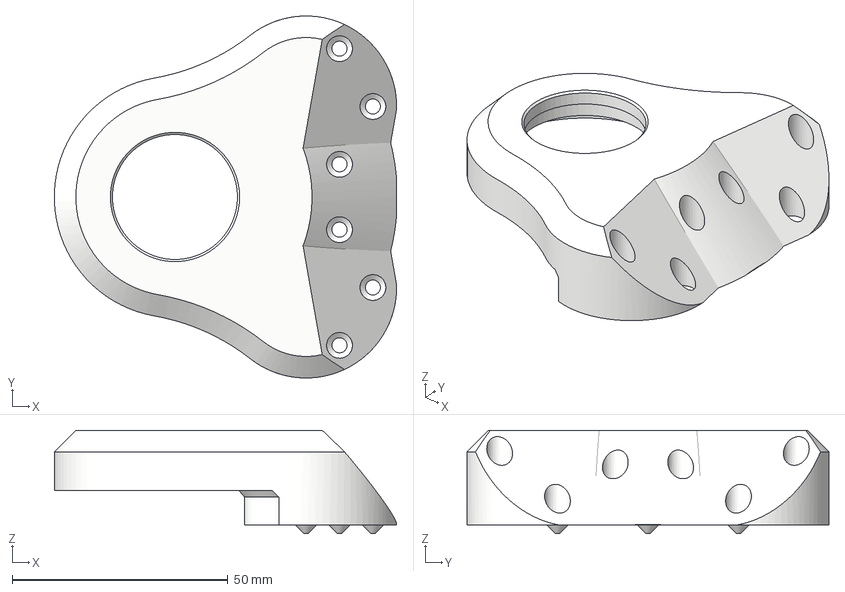
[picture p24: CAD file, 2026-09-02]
Hex3_resources/cad/release_3mfs/leg_individuals/s1_motor_bearing_mount.3mf
79.4 x 84.0 x 24.0 mm

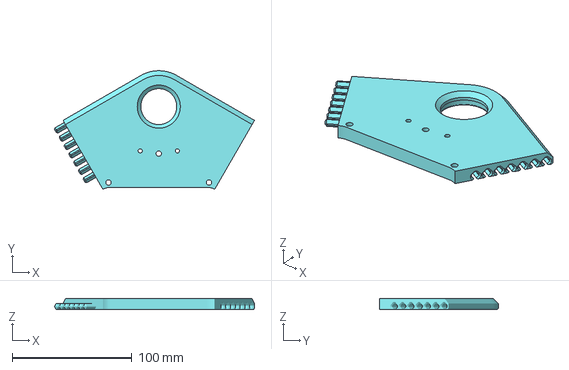
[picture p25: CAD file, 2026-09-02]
Hex3_resources/cad/release_3mfs/base_individuals/base_flat_x12.3mf
167.1 x 99.1 x 9.00 mm

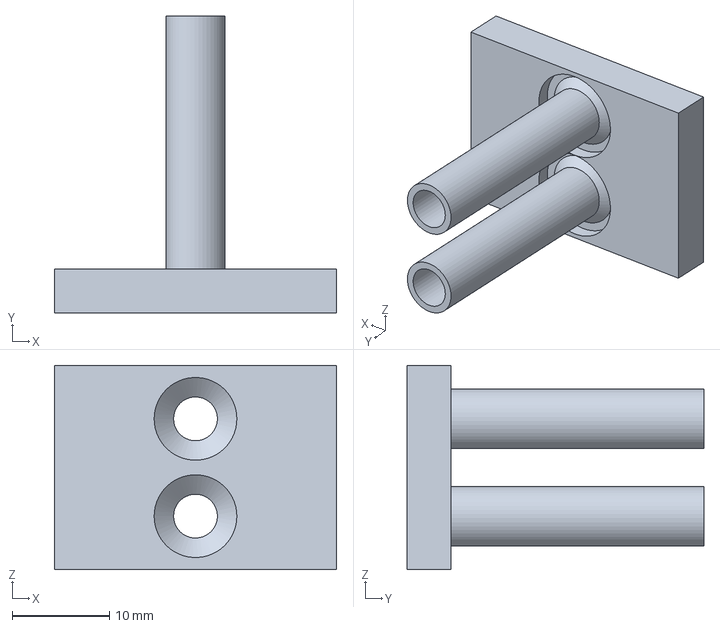
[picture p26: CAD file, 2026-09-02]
Hex3_resources/cad/release_3mfs/leg_individuals/spring_aligner.3mf
29.0 x 30.5 x 21.0 mm

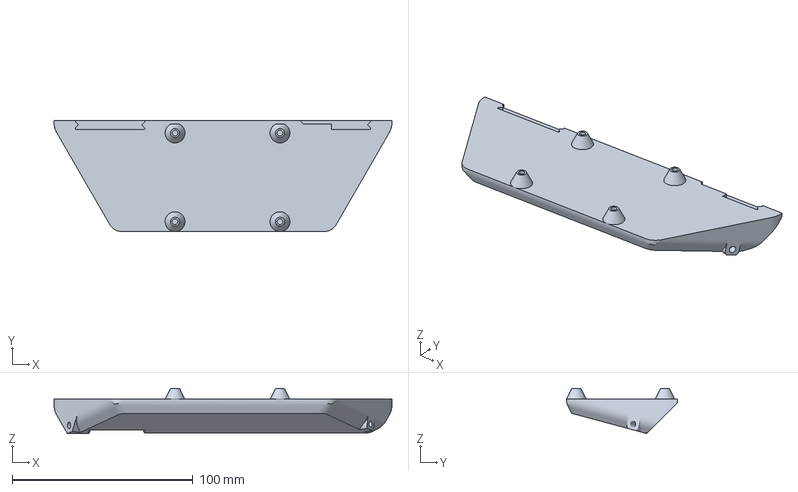
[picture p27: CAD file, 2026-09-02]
Hex3_resources/cad/release_3mfs/base_individuals/base_electronics_mount.3mf
186.8 x 61.5 x 25.0 mm

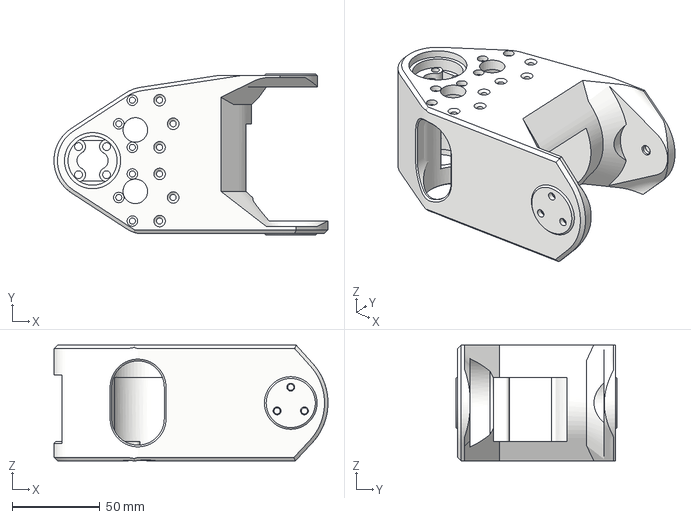
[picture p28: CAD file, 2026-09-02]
Hex3_resources/cad/release_3mfs/leg_individuals/s1.3mf
156.1 x 92.0 x 66.0 mm

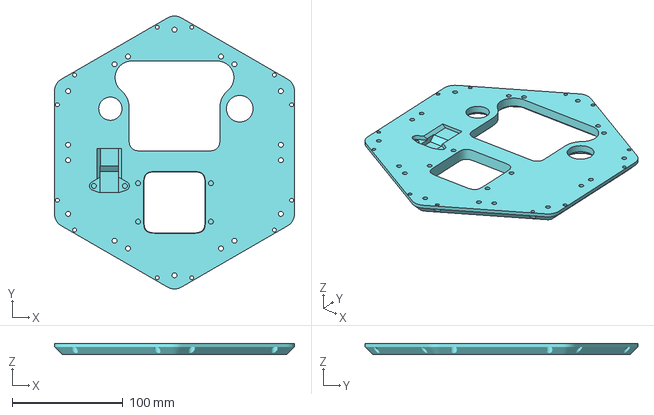
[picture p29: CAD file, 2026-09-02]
Hex3_resources/cad/release_3mfs/base_individuals/base_lower.3mf
216.5 x 246.2 x 10.1 mm

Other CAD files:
Hex3_resources/cad/release_3mfs/leg_individuals/toe tip.3mf
Hex3_resources/cad/release_3mfs/base_individuals/base_lidar_mount.3mf
Hex3_resources/cad/release_3mfs/leg_individuals/s1_encoder_cover.3mf
Hex3_resources/cad/release_3mfs/leg_individuals/s2_magnet_mount.3mf
Hex3_resources/cad/encoder_insertion_tool.f3d
Hex3_resources/cad/release_3mfs/leg_individuals/s0.3mf
Hex3_resources/cad/release_3mfs/leg_individuals/s0_gear_cover.3mf
Hex3_resources/cad/release_3mfs/leg_individuals/s0_gear_cover_spacer.3mf
Hex3_resources/cad/release_3mfs/leg_individuals/s1_bearing_holder_x2.3mf
Hex3_resources/cad/release_3mfs/leg_individuals/s1_motor_bearing_holder.3mf
Hex3_resources/cad/release_3mfs/leg_individuals/s1_motor_cover.3mf
Hex3_resources/cad/release_3mfs/leg_individuals/s2_bearing_screw_mount.3mf
Hex3_resources/cad/release_3mfs/leg_individuals/s2_connector_short.3mf
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

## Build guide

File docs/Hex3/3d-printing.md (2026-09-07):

# 3D Printing

## Print Recommendations

!!! note
    PETG can be used, but we recommend printing in ABS or ASA for better strength and heat resistance.

All structural parts are sliced in PrusaSlicer using the `0.2mm STRUCTURAL` print profile on a Prusa Core ONE.

| Parts | Walls | Infill | Supports |
|---|---|---|---|
| Default (most parts) | 4 | 30% triangles | As needed |
| `base_core` & toes | 12+ | 30% triangles | As needed |

- `base_core` sees the highest structural loads, so it's printed with 12+ walls to make them effectively solid rather than relying on infill.
- The toes are also printed with these settings as they will wear down over time.

CAD files for Hex3 are available in the [GitHub](https://github.com/ManufacturedMotion/Hex/tree/main/Hex3_resources/cad) or via our [Hex3 Printables project](https://www.printables.com/model/1831798-hex3-an-opensource-hexapod-platform)

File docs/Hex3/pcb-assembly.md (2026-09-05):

# PCB Assembly

This page is intended to collect assembly instructions for the Hex3 printed circuit boards, including the two leg PCB revisions and the main PCB.

## Tools and Components

- Soldering iron and soldering accessories
- Flux and solder
- Multimeter for continuity and polarity checks
- PCB holder or vise (recommended)
- ESD-safe handling practices (recommended)
- Relevant parts, BOM and board revision documentation

## Leg PCB

There are two versions of the Leg PCB available for building the Hex3 platform: **V2.0** and **V3.2**. Both versions are fully functional and can be used to build a complete Hex3 platform. The main differences are in **assembly method, thermal management, PCB cost, and XIAO RP2350 reusability.**

V2.0 is the simpler and more cost-effective design, with components that are straightforward to assemble by hand. V3.2 is a more refined design focused on improved thermal performance and easier XIAO RP2350 replacement/reuse, but comes with increased PCB cost and some additional assembly considerations.

The following sections summarize the main pros and cons of each version.

Leg V2.0:
- through hole diode
  - to be soldered by hand
- DRV8871 motor driver chips do not get additional cooling
  - external heat sinks can still be applied, but the PCB layout and design was not focused on heat dissipation
- XIAO RP2350 soldered directly to the PCB
  - cannot repurpose / reuse the XIAO board 

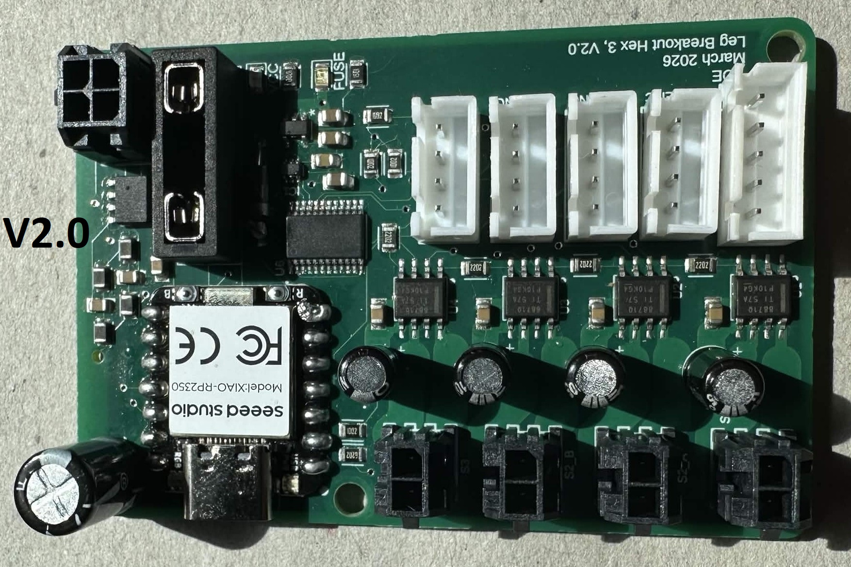
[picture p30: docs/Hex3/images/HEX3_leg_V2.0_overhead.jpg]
Hex3 Leg V2.0


Leg V3.2:
- SMT diode
  - less hand soldering required, but you have to add this part to your ASM part list when placing the order
- Design has heavy emphasis on increased cooling for the DRV8871 motor driver chips
  - 2 oz internal copper pours (this increases the price quite a bit!)
  - via stitching for GND plane 
- POGO pin option for XIAO RP2350 board
  - can re-use the XIAO on other projects if desired (no longer soldered directly to the PCB)
  - POGO pin spacing is sensitive -- you need specific male/female header pins to get a good distance for the POGO compression

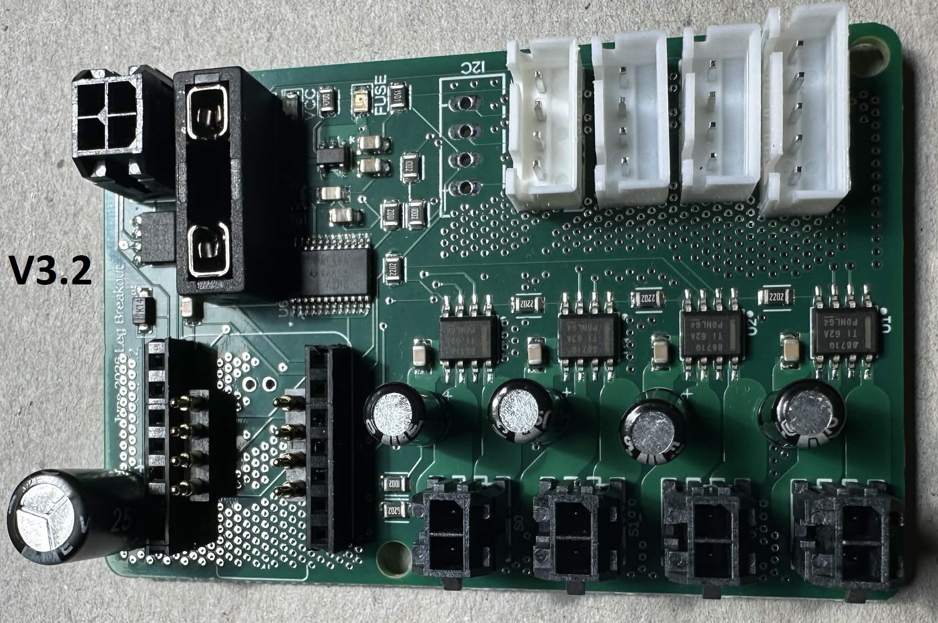
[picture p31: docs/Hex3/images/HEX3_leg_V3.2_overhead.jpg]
Hex3 Leg V3.2


### Parts List (for 1 leg PCB)
- 1x Xiao RP2350 (no headers attached)
- 1x 3557 Fuse block
- 3x 4 Pin JST Board Connector
  - grab a 4th 4 Pin JST if you will use the extra I2C connection! (this is an optional breakout connection. Our current software does not require this to be connected)
- 1x 5 Pin JST Board Connector
- 1x 4 Pin Molex Board Connector
- 4x 2 Pin Molex Board Connector
- 4x 22uF Radial Capacitor
- 1x 470uF Radial Capacitor
- 1x Leg PCB (V2.0 OR V3.2)
  - V2.0:
    - 1x 1N5819 Diode
  - V3.2:
    - 2x 4 Pin POGO Connector (Optional)
    - 2x 7 Pin Short Male Header Pin (Optional)
    - 2x 7 Pin Short Female Header Pin (Optional)

### Recommended Assembly Order

1. We have found it is easiest to start with the Xiao RP2350. If you are using V3.2 of our leg PCB you can opt to use header pins for this connection. V2.0 does not have header pin support
  - surface mounted Xiao suggestions
    - we have had good success by starting with the top pins on the Xiao. Pick any two diagonal pins, and solder these joints with a small amount of solder. Be sure to visually inspect the top pins and the alignment with the PCB's solder pads such that each side of the Xiao is evenly spaced, and all pins are centered.
    - once you have two connections on the top, flip the PCB over. Inspect the through holes on the bottom of the PCB, and make sure the solder pads on the bottom of the Xiao are centered to these holes. If the holes are not centered, flip the board. Heat one corner of the Xiao to loosen it, and gently apply a force to rotate it. Repeat until the holes are centered with the pads on the bottom of the Xiao.
    - once the bottom holes are aligned, you may now solder all of the pins on the top of the Xiao board
    - once the top is finished, move to the bottom. For these connections we found it is best to use a thin soldering iron tip, and apply heat to the hole and Xiao SMT pad at the same time. Once the copper has had time to heat up, fill the hole with solder, and let the soldering iron remain in the solder for a bit to ensure all solder & copper is warm. Remove the soldering iron and make sure the hole was not overfilled, and there are no shorts to the neighboring holes
  - Header pin Xiao suggestions
    - first solder the female header pins to the PCB
    - then solder the male header pins to the Xiao board
      - if you are using the header pins and pogo pins from our Hex3 BOM, we suggest soldering the male pins to the Xiao in a unique fashion, to ensure the pogo pins make solid contact with the pads on the bottom of the Xiao
      - instead of having the Xiao rest on top of the male header pins, insert the pins through the top of the Xiao. (see picture below)
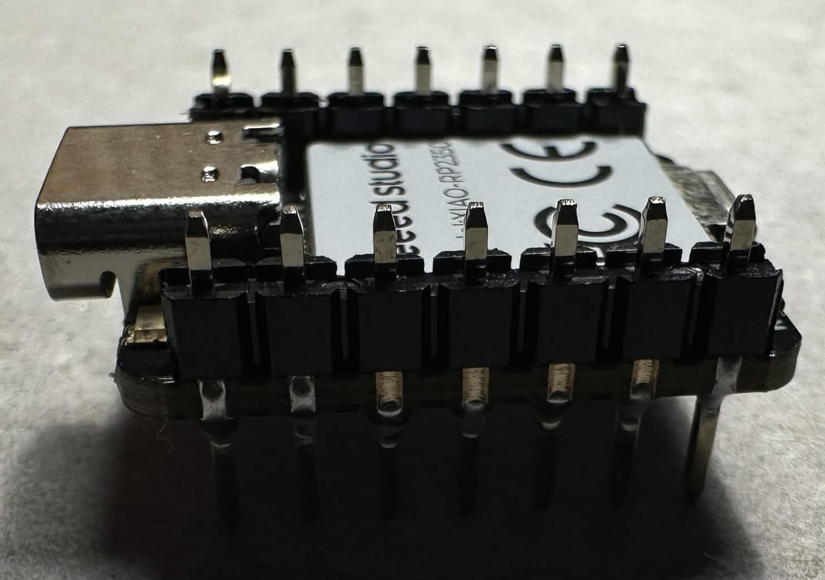
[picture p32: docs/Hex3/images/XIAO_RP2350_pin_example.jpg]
Hex3 RP2350 Header Example
      
    - place the pogo pins on the PCB, and then plug the Xiao into the female header pins. Inspect the alignment of the tip of the pogo pins and the pads on the bottom of the Xiao. If the alignment is good, solder the pogos to the PCB
1.A. If you are using **V3.2 of the board you may skip this step**, as the diode is now SMT and part of the PCB ASM. If you are using **V2.0, solder the diode to the board now. The cathode of the diode should be on the side closer to the Xiao**
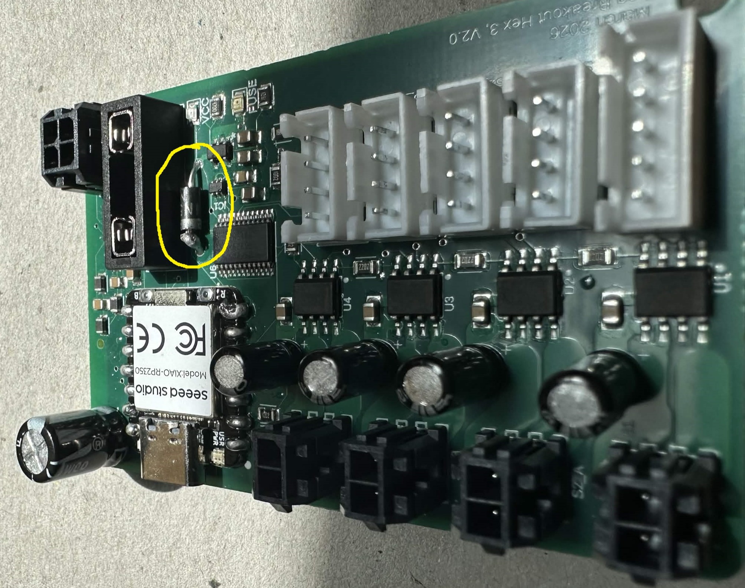
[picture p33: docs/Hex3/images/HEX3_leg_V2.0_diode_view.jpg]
Hex3 Leg PCB Diode

2. Solder the 3557 fuse block to the PCB. **Be sure to hold the soldering iron to the pins of the block for long enough such that an adequate amount of heat builds up before applying your solder**
3. JSTS
  - solder the 4 pin JSTs for the encoders
  - optionally, you may solder a 4th JST to the I2C breakout connection
  - solder the 5 pin JST for the toe sensor
4. molex
  - solder the 4 pin Molex for the main power supply / canbus connection with the main PCB
  - solder the 2 pin Molex connectors for the motors
5. capacitors
  - solder the 22uF capacitors for the motor circuits. **Be sure to follow the correct polarity when placing the capacitors! The cathode of the 22uF capacitors should face towards the 2 pin Molex connectors**
  - solder the 470uF capacitor for the Xiao. **Be sure to follow the correct polarity when placing the capacitors!**
    - **for V2.0 the cathode faces towards the fuse block / 4 pin Molex connector**
    - **for V3.2 we changed the alignment, so all capacitors share the same orientation. The cathode for the 470uF capacitor on V3.2 should face towards the Xiao USB**

### Special Leg PCB Version Differences (DO NOT SKIP THIS!!)

#### For users with leg PCB V2.0:
- the traces for the split termination canbus will need to be cut! See the below image and cut the traces in the same location (these traces are on the bottom of the PCB)
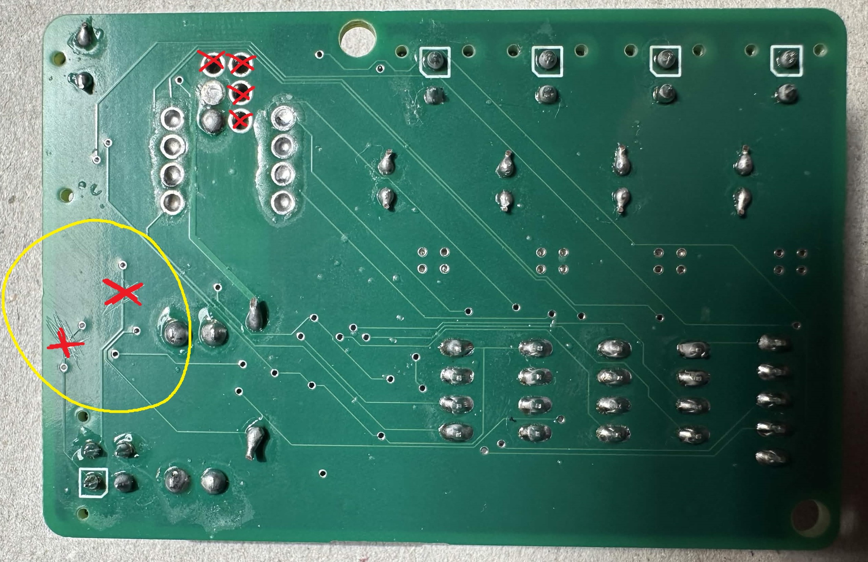
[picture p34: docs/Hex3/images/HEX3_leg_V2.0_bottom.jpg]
Hex3 V2.0 PCB Cut Traces


#### For users with leg PCB V3.2:
- there is a required software update to account for the new design's connector positions
- please make the following updates to our [leg.cpp](https://github.com/ManufacturedMotion/Hex3/blob/main/real_time/xiao_code/lib/HexapodController/src/leg.cpp) file before uploading to your Xiao boards
  
`Line 53`
```
  -  axes[0].link(D8, D10, 5, mux);
  +  axes[0].link(D17, D18, 7, mux);
```
`Line 55`
```
  -  axes[2].link(D17, D18, 7, mux);
  +  axes[2].link(D8, D10, 5, mux);
```

**your file should look like this after making the updates:**
```
    axes[0].link(D17, D18, 7, mux);
    axes[1].link(D11, D12, D15, D16, 6, mux);
    axes[2].link(D8, D10, 5, mux);
```

### Verification Checks

- Check for solder bridges, cold joints, or misaligned components.
- Verify connector orientation and polarity before powering the board.
- Don't forget to insert a mini blade fuse into the fuse block before your poweron test! For the leg board we are using 10A fuses.
- We suggest connecting each leg board to a power supply (one at a time) and confirming the LEDs and Xiao operate properly prior to testing connection with the main PCB.
- Don't forget to trim the extra length of the legs on the through hole radial capacitors to prevent any shorted connections!

<u>Repeat the above instructions 5 more times so you have a total of 6 leg PCBs!</u>

## Main PCB

### Parts List

- 1x 3557 Fuse Block
- 1x 10uF Radial Capacitor
- 1x 470uF Radial Capacitor
- 1x XT60 Board Connector
- 1x 2 Pin Male Header Pin
- 1x 2 by 40 Female Header Pin for Raspberry Pi
- 2x DC-DC Buck Converter
- 6x 4 Pin Molex Board Connector
  - we actually have solder connections for up to 8x 4 Pin Molex Board Connectors! Since it is a shared canbus and power connection, you can solder your 6 to any of the connection points. You can also choose to solder the other breakouts and update the software to use 8 legs!
- 2x 3 Pin JST Board Connectors
- Optional JST Breakouts
  - we included optional breakouts for the following Pi connections:
    - 1x 3 Pin JST - LED Ring 
    - 1x 3 Pin JST - PWM0
    - 1x 3 Pin JST - PWM1
    - 3x 4 Pin JST
      - UART0
      - UART1
      - I2C
    - 4x 5 Pin JST (numbered pins refer to Pi GPIO pins)
      - 5V, 4, 27, 22, GND
      - 5V, 11, 6, 26, GND
      - 5V, 18, 23, 25, GND
      - SPI1 

### Recommended Assembly Order

1. Solder the XT60 Connector to the PCB. **Be sure to hold the soldering iron to the pins of the connector long enough for an adequate amount of heat to build up before applying your solder**
2. Solder the 3557 fuse block to the PCB. **Be sure to hold the soldering iron to the pins of the block for long enough such that an adequate amount of heat builds up before applying your solder**
3. Solder the 2x40 Female Header Pin Connector to the board, **with the pins protruding through the top of the PCB**. The main PCB will plug into the Pi and rest on top of it. 
4. Solder the DC-DC Buck Convertors to the PCB. **Be sure to get the proper polarity alignment. The block on the buck converters should be facing upwards, away from the PCB. The voltage input for the DC-DC converters should be on the left side of the board, closest to the XT60 connector.** 
5. Add a 1x2 Male Header connection to the slot in the center of the board. Alternatively, you can just short these two pads together, or solder a looped wire, etc.. This connection is used to enable a 120 Ohm resistor on the canbus network.
  - if you are using the Male Header, once it is soldered to the PCB, short the pins with a jumper shunt
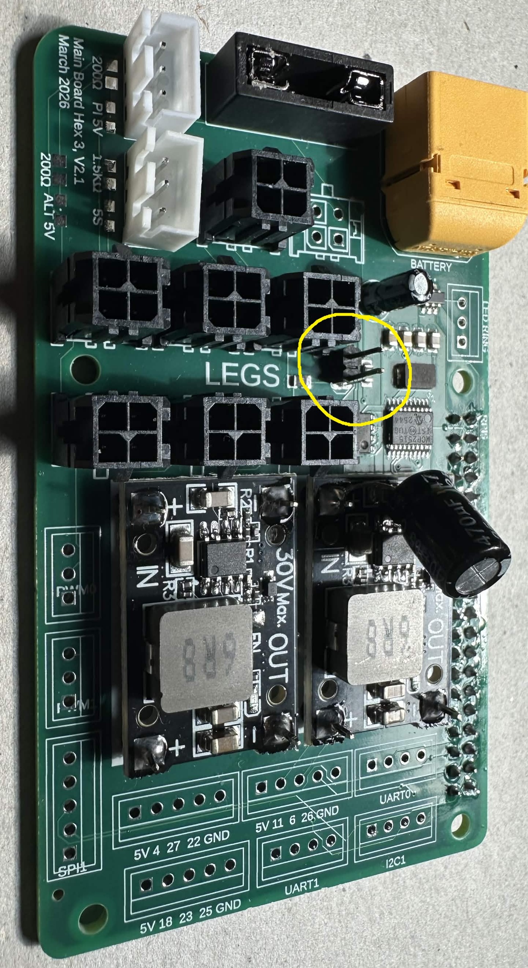
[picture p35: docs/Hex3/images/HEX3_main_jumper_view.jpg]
Hex3 Main PCB Jumper

6. Solder your JSTs
  - At a minimum, the required connections are the two 3 Pin JSTs for the cooling fans
  - The other JSTs (outlined above) are all optional
7. Solder your Molex connectors
8. Capacitors
  - Solder the 10uF capacitor to the slot on the board. **Be sure to follow the correct polarity when placing the capacitor! The cathode of the 10uF capacitor should face towards the bottom of the board (facing away from the XT60 / towards the Molex's)**
  - Solder the 470uF capacitor across the input terminals on the upper DC-DC converter. **The cathode should be facing the negative input, and the anode should be facing the positive input**
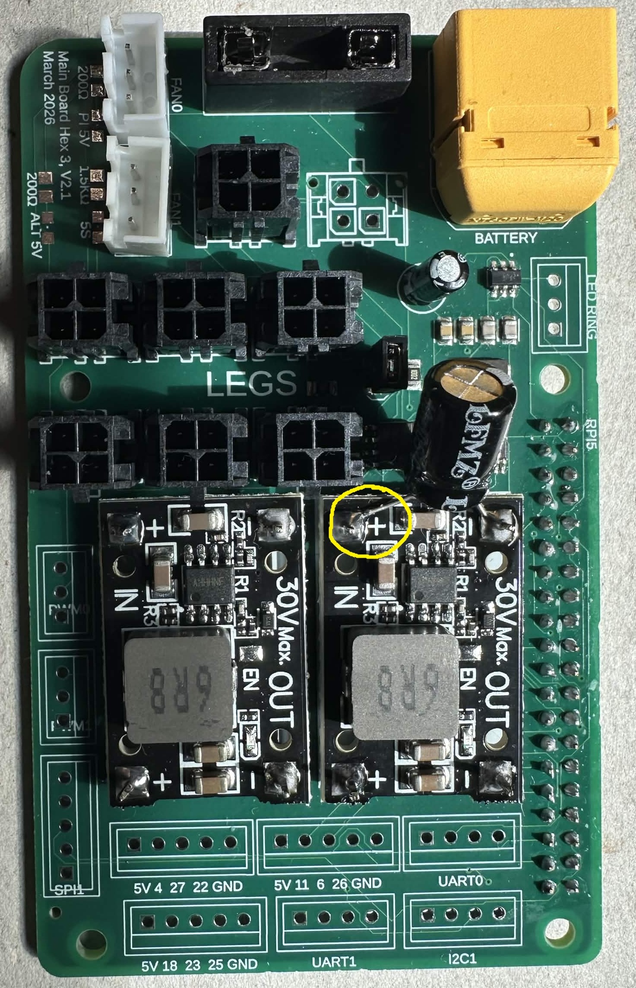
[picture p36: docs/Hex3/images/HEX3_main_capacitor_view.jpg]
Hex3 Main PCB Capacitors


### Verification Checks

- Verify that all connectors are installed in the correct orientation.
- Check for shorts around power paths and regulators.
- Don't forget to insert a mini blade fuse into the fuse block before your poweron test! For the leg board we are using a 20A fuse.
- We suggest first connecting the main PCB to a power supply to ensure proper voltage is supplied to the Pi's 5V input and the 24V line for the 4 Pin Molex connectors. It is strongly encouraged that you do this test BEFORE connecting your Raspberry Pi.
- After ensuring proper voltage levels, you can connect the main board to a leg board and test that the leg board receives power once you power on the main board. 
- Don't forget to trim the extra length of the legs on the through hole radial capacitors to prevent any shorted connections!

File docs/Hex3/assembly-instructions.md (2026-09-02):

# Assembly Instructions

This section walks through building a Hex3 from parts to a walking hexapod.

## Tools and Components

- A full BOM of parts needed can be found [here](https://docs.google.com/spreadsheets/d/1jHR1j3dNIgRCcadYxqtaftRhhn8tEC1XY8og_EQwXEU/edit?usp=sharing).
- Tools required:
    - 2.00mm hex key (allen-key):
        - For use on Raspberry Pi and LiDAR.
    - A 2.5mm hex key (allen-key)
        - We recommend also using a 2.5mm drill bit, as manually tightening all the screws is a herculean task.
        - All the hardware, with the exception of the Raspberry Pi and LiDAR connections use 2.5mm hex.
    - Soldering iron and soldering accessories.
    - Flux and solder.
    - Heat set insert bit for soldering iron.
    - Multimeter for continuity and polarity checks.
    - PCB holder or vise (recommended for [PCB Assembly](pcb-assembly.md)).
    - Wire cutter
    - Wire stripper for the gauges listed [here](electronics-setup.md#wire-lengths).
    - A clamp
        - Not required but highly recommended for press fits.
    - JST crimp tool
    - Terminal Connector crimp tool
        - Highly recommended but not required as you could directly solder these connections.
    - Misc. pliers, tweezers, etc., for removing supports and other general uses.

- Additional materials required:
    - Multipurpose synthetic grease for gears

## Stages

The build is split into six stages, meant to be followed roughly in order:

1. [3D Printing](3d-printing.md) — print recommendations for the body and legs.
    - Get these prints kicked off and have them running in the background while working on other assembly steps.
2. [PCB Assembly](pcb-assembly.md) — soldering the leg PCBs and the main PCB.
    - Once completed, you should have at least:
        - 1x mainboard
        - 6x leg boards
3. [Electronics Setup](electronics-setup.md) — power wiring, Raspberry Pi wiring, and wire harness lengths.
    - Once completed, you should have at least:
        - 1x power assembly
        - 18x encoders
        - 6x toe time-of-flight sensors (experimental feature; not currently implemented in software)
4. [Mechanical Assembly](mechanical-assembly.md) — assembling the printed parts and hardware into the hexapod body and legs.
    - Once completed, you should have the hexapod fully assembled, with all 6 legs ready for calibration.
5. [Real-Time Firmware](firmware-setup.md) — building, flashing, and calibrating the per-leg Xiao RP2350 firmware.
6. [Raspberry Pi Configuration](raspberry-pi.md) — flashing the SD card and getting Raspberry Pi OS, Docker, and ROS2 all configured.

Once all six stages are complete, head to [Common Commands](common-commands.md) to get the hexapod moving.

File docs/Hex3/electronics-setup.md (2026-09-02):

# Electronics Setup

## Power Wiring

The power for the Hexapod comes from a 5Ah Milwaukee M18 battery. Power is sent to the main PCB and distributed from there. A relay handles turning the Hexapod on and off via a latching power switch.

The connections are: 

| Component | Connection |
|---|---|
| M18 Battery (+) | WAGO → Relay Pin 30 and latching switch input |
| M18 Battery (-) | WAGO → Relay Pin 85 and robot ground |
| Latching Switch Input | Battery + |
| Latching Switch Output | Relay Pin 86 |
| Hexapod Power (+) | Relay Pin 87 |
| Hexapod Ground (-) | Battery - |

The JD2914 relay pinout is:

| Relay Pin | Function | Connects To | Wire Color (Recommended) | Notes |
|---|---|---|---|---|
| **30** | Common (COM) | Battery | Red | Main power input from the M18 battery |
| **87** | Normally Open (NO) | Robot power **+** | Red | Connected to Pin 30 when the relay is energized |
| **87a** | Normally Closed (NC) | *Not connected* | — | Leave unused and insulated |
| **85** | Coil (-) | Battery **-** | Black | Relay coil ground |
| **86** | Coil (+) | Output of the latching power switch | Red | Energizes the relay when the switch is ON |

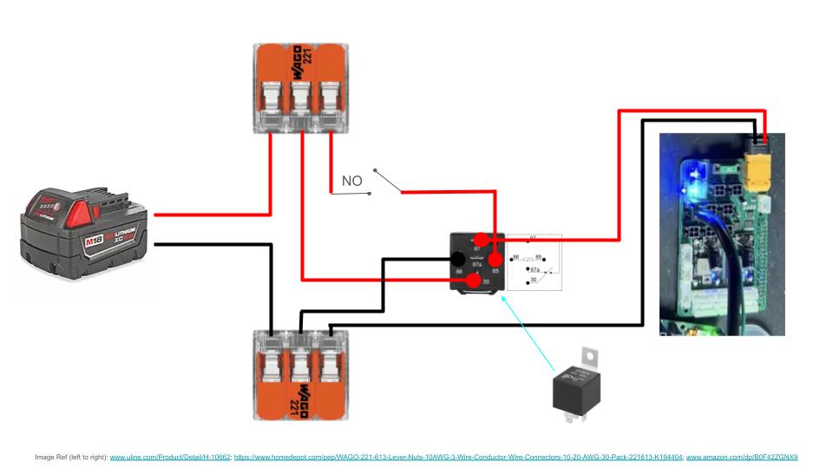
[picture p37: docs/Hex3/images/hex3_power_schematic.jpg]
Hex3 Power Schematic


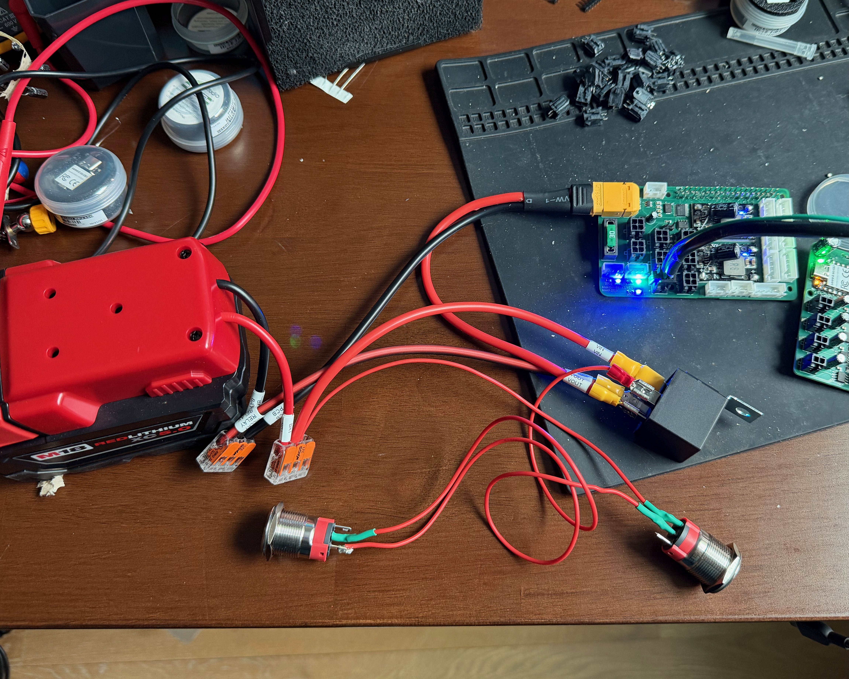
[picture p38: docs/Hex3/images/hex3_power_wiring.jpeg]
Hex3 Power Wiring


---

## Raspberry Pi Wiring

!!! note
    Due to noise from the buck converters + relay combination, the Raspberry Pi 5 needs to be booted after the Hexapod is powered on. 

This power cycling can be easily handled via the Raspberry Pi 5's built in power button vias. We recommend using right angle headers and wiring in a momentary power button to trigger the restart (Hex3's lid has a hole for a momentary power switch).

Follow [these Raspberry Pi docs](https://www.raspberrypi.com/documentation/computers/raspberry-pi.html#add-your-own-power-button) on adding your own power button.

---

## Wire Lengths

/// html | div.grid

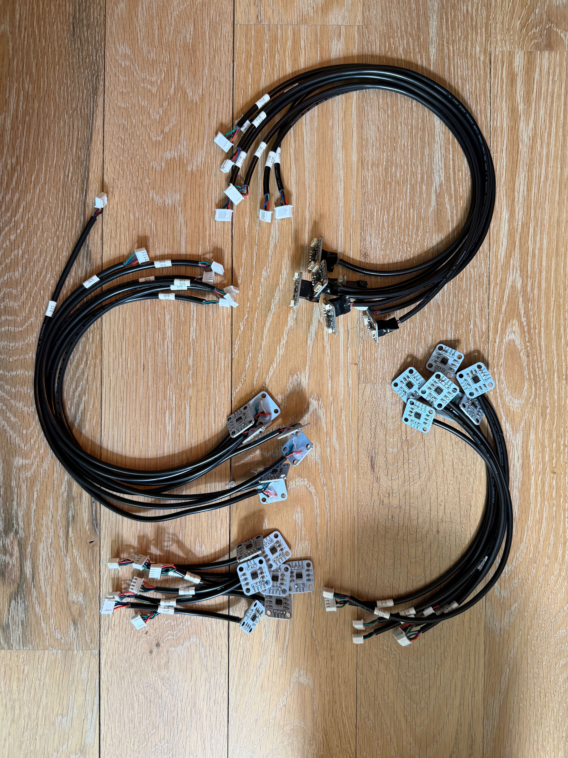
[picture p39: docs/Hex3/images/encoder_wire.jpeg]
Encoder wire harnesses


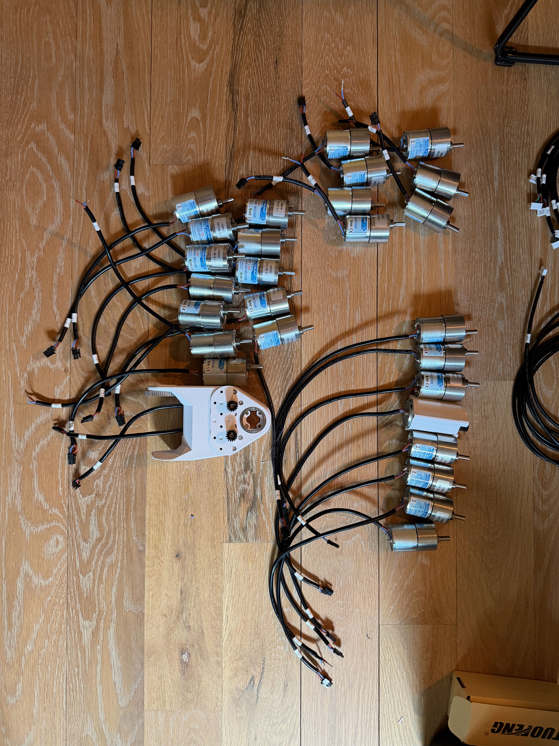
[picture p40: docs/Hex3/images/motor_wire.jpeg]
Motor wire harnesses


///

| Connection | End 1 Connector | End 2 Connector | Wire Length | Wire Type | Quantity |
|:---|:---|:---|---:|:---|---:|
| S0 Encoder <> Leg PCB | None | 4 Pin JST XH Female Socket Housing | 120 mm | 4 Conductor 24 AWG | 6 |
| S0 Motor <> Leg PCB | None | 2 Pin Molex Microfit 3.0 Plug | 130 mm | 2 Conductor 18 AWG | 6 |
| S1 Encoder <> Leg PCB | None | 4 Pin JST XH Female Socket Housing | 250 mm | 4 Conductor 24 AWG | 6 |
| S1 Motor <> Leg PCB | None | 2 Pin Molex Microfit 3.0 Plug | 265 mm | 2 Conductor 18 AWG | 6 |
| S2 Encoder <> Leg PCB | None | 4 Pin JST XH Female Socket Housing | 405 mm | 4 Conductor 24 AWG | 6 |
| S2 Motor <> Leg PCB | None | 2 Pin Molex Microfit 3.0 Plug | 365 mm | 2 Conductor 18 AWG | 6 |
| Time of Flight (Toe) Sensor <> Leg PCB | 4 Pin JST XH Female Socket Housing | 5 Pin JST XH Female Socket Housing | 450 mm | 4 Conductor 24 AWG | 6 |
| Main PCB <> Leg PCB | 4 Pin Molex Microfit 3.0 Plug | 4 Pin Molex Microfit 3.0 Plug | 185 mm | 2 Conductor 18 AWG + 2 Conductor Twisted Pair 24 AWG | 5 |
| Main PCB <> Leg PCB | 4 Pin Molex Microfit 3.0 Plug | 4 Pin Molex Microfit 3.0 Plug | 250 mm | 2 Conductor 18 AWG + 2 Conductor Twisted Pair 24 AWG | 1* |

*Used for the leg behind the battery connection.

---

## Encoders

!!! note
    The encoder's DIR pin must be grounded. This is done directly on the encoder board with a small jumper wire between DIR and GND — it is separate from the 4 conductor harness below.

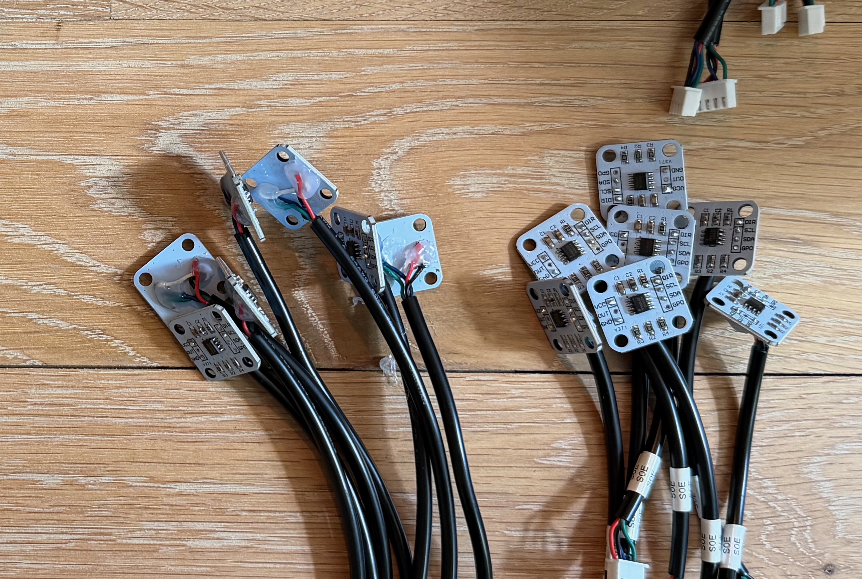
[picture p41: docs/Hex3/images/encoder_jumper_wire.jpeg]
Encoder Jumper Wire


If using our 4 conductor wire harnesses (see [Wire Lengths](#wire-lengths) above), we recommend wiring:

| Wire Color | Signal | JST Pin |
|---|---|---|
| Red | VCC | 1 |
| Black | GND | 2 |
| Blue | SCL | 3 | 
| Green | SDA | 4 |

...for consistency with the connector order on the board. 

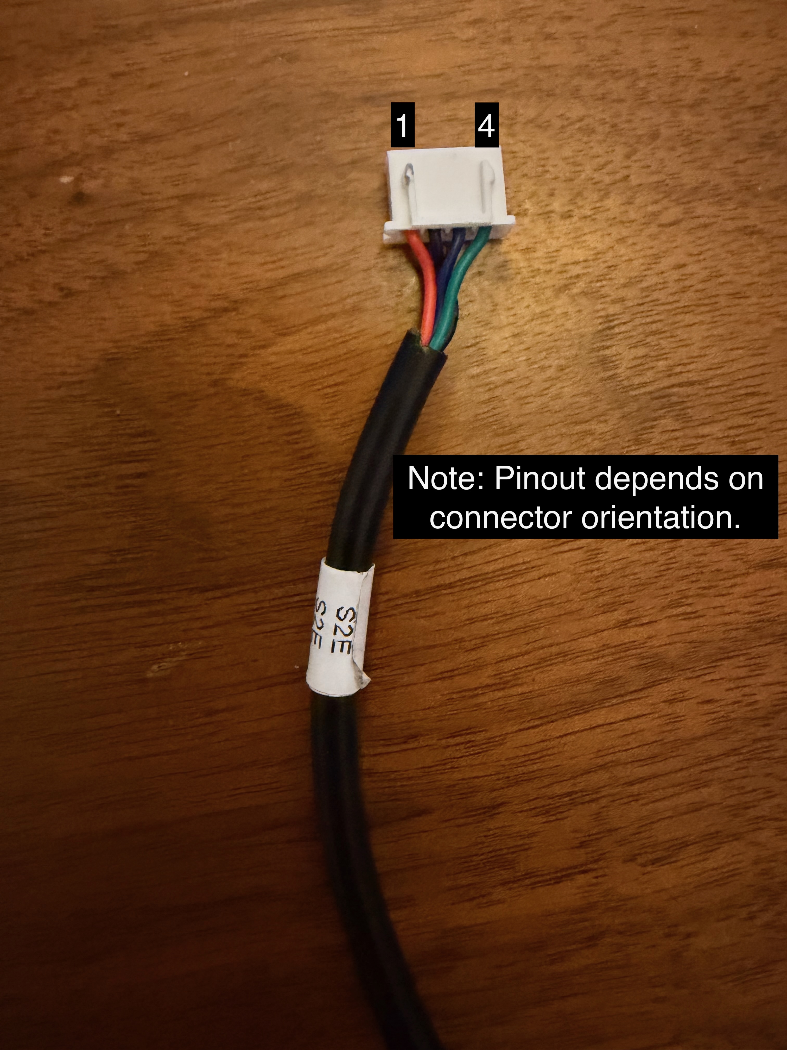
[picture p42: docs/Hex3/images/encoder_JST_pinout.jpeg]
Encoder JST Pinout


!!! note
    When soldering the encoder wires directly to the S0/S1/S2 encoder boards, keep the solder joints close to flush with the board. Solder that sits proud can stick up higher than the nearby capacitors, which will prevent the encoder from sitting flush once mounted (see the [Mechanical Assembly](mechanical-assembly.md) note that encoders must be installed fully flush).

## Motors

The polarity of the wiring to the motors does not matter, but you should be consistent with your wiring. The polarity choice will affect [these constants in your config.hpp file](https://github.com/ManufacturedMotion/Hex3/blob/5c3b54bb8905e35a4c63c192355dc47a30cfa154/real_time/xiao_code/lib/HexapodController/src/config.hpp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). If you connect the negative terminal of the motor to pin 1 of the Molex connector, you will end up with the following axis inversion values: `{true, false, false}`

## Leg PCB <-> Main PCB Connection Cables 

If using our 4 conductor wire harnesses (see [Wire Lengths](#wire-lengths) above), we recommend wiring:

| Wire Color | Signal | Molex Pin |
|---|---|---|
| Purple | GND | 1 |
| Red | VCC | 2 |
| Black | CAN LOW | 3 | 
| White | CAN HIGH | 4 |

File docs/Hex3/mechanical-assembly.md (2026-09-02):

# Assembly Steps

!!! note
    - This SOP assumes you have all of the necessary parts 3D printed (refer to the [BOM](https://docs.google.com/spreadsheets/d/1jHR1j3dNIgRCcadYxqtaftRhhn8tEC1XY8og_EQwXEU/edit?usp=sharing) and use the [Print Recommendations](3d-printing.md))
    - Parts might look slightly different from the images / CAD screenshots here. Always use the newest version available on the Github.

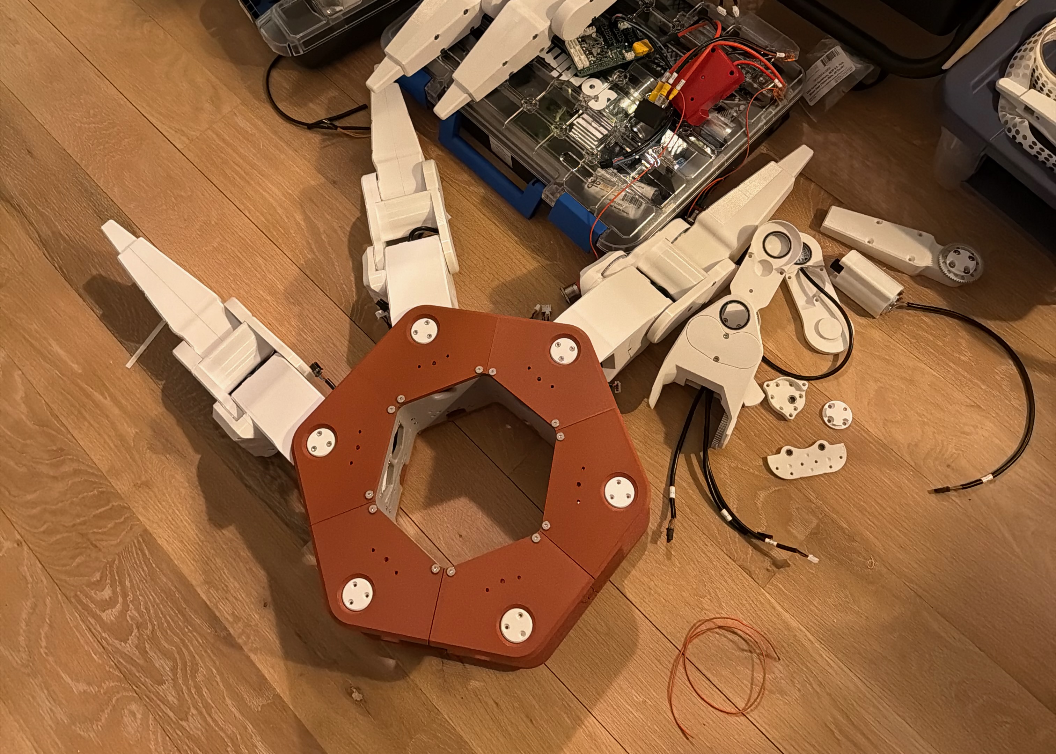
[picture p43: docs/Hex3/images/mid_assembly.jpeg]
Mid Assembly


---
## Leg Assembly

It is up to you how you would like to batch the parts needed for a leg assembly. You can add the heatsets to one part at a time, all the parts for a leg, or all the parts for all the legs. These instructions cover assembly on a per leg basis, so we will prep all the parts for a single leg at once.

!!! note
    Refer to the CAD if any screw, heatset, or other placement is unclear. All hardware is included in the Fusion360 assembly.

### Part Preparation

1. Install all of the M3 heatset inserts:

    1. [S0] 4x for the encoder mount.
    1. [S1] 4x for the encoder mount.
    1. [S1] 6x for the base upper and base lower connections.
    1. [S1] 2x for the motor cover.
    1. [S2] 3x onto the S2 gear side.
    1. [S2] 4x for the encoder mount.
    1. [S2] 2x for the encoder magnet mount.
    1. [S3] 2x for the encoder magnet mount.

1. Install all of the M4 inserts:

    1. [S1] 4x for the hub gear connection.
    1. [S2] 4x for the hub gear connection.
    1. [S2] 6x for the long S2 connector.
    1. [S3] 4x for the hub gear connection.
    1. [S3] 4x on the S3 gear side to connect the pieces together.
    1. [S3] 2x in the toe piece.

1. Press fit the encoder magnets (note: these must be perfectly flush, and not installed at an angle):

    1. [S1] 1x directly on the part.
    1. [S2] 1x on the removable magnet holder.
    1. [S3] 1x on the removable magnet holder.
    1. Install the S2 and S3 magnet holders onto those parts.

1. Press fit the small motor bearings (6mmx10mmx3mm). These bearings get installed on any parts that mate with the shaft of a motor:

    1. [S0] 1x installed on the S0 gear cover. 
    1. [S1] 2x installed on the S1 motor bearing holder.
    1. [S2] 1x installed on the S2 short connector.

1. Press fit the large bearings (25x32x4mm).

    1. [S1] 2x installed in S1.
    1. [S1] 1x installed in the S1 motor bearing mount.
    1. [S2] 1x installed on the S2 bearing side.
    1. [S2] 1x installed on the S2 gear side.

1. Install the encoders using the [encoder helper tool](https://github.com/ManufacturedMotion/Hex/tree/main/Hex3_resources/cad), ensuring that they are fully flush against the part. Be careful not to scrape the PCB when installing. Screws should also be removed from the encoder once mounted.

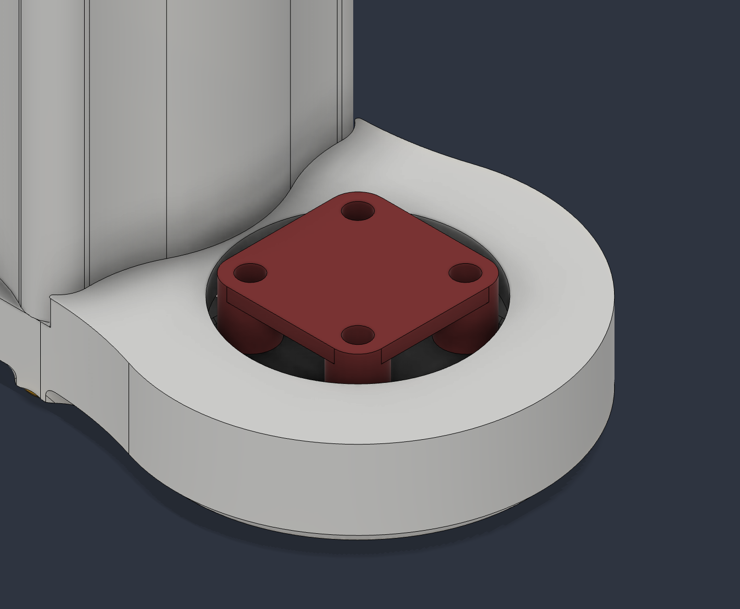
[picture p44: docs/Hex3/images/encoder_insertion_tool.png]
Encoder Insertion Tool
    

    1. [S0] 1x encoder installed.
    1. [S1] 1x encoder installed with cover (2 screws remain through the cover).
    1. [S2] 1x encoder installed bearing side.

### Assembly

!!! note
    The grub screw placement on the 15-tooth gear (this is the small one!) is critical, and varies per motor, so please refer to the CAD for confirmation.
    We also recommend applying some Blue Loctite to the grub screw when attaching the gear to the motor shaft.

#### S0 Assembly

1. Attach the motor to S0 using two M3x08 screws.
1. Add in the S0 gear cover spacer.
1. Add the 15 tooth gear to the S0 motor shaft with the **grub screw closest to the motor**.
1. Attach the S0 gear cover with two M3x18 screws.
1. Leave the rest of the assembly to a later part.

#### S1 Assembly

1. Install the two motors into S1, only using the 3 screws closest to the encoder on each motor. Route the wires out the back of S1.
1. Route the encoder wire out the back of S1, through the two motors.
1. Add in the S1 motor bearing holder.
1. Add a 15 tooth gear on each S1 motor shaft with the grub screw **closer to motor base**.
1. Install the hub gear using four M4 screws.
1. Install the S1 motor cover using two M3 screws.
1. Leave the rest of the assembly to a later part.

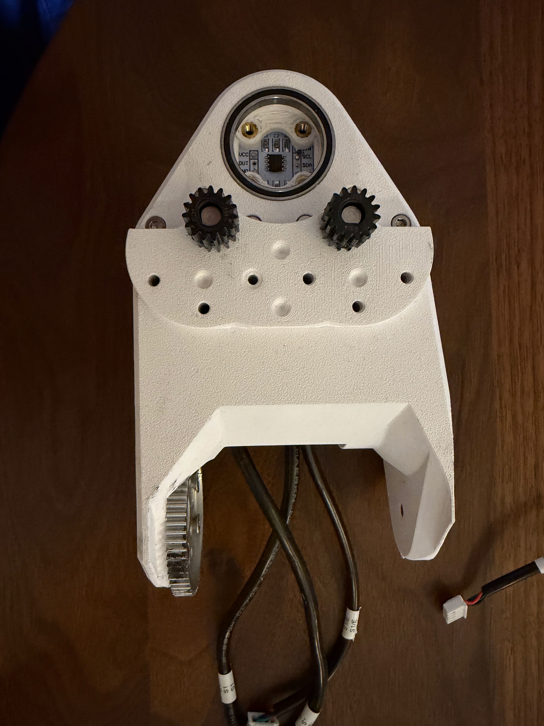
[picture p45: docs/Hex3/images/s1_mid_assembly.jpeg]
S1 Mid Assembly


#### S2 Assembly

1. Install the S2 motor through both the S2 short and S2 long pieces. Connect using 6 M3x08 screws.
1. Add the 15 tooth gear to the S2 motor shaft with the grub screw **further** from the motor.
1. Install the hub gear using 4x M4 screws.
1. Leave the rest of the assembly to a later part.

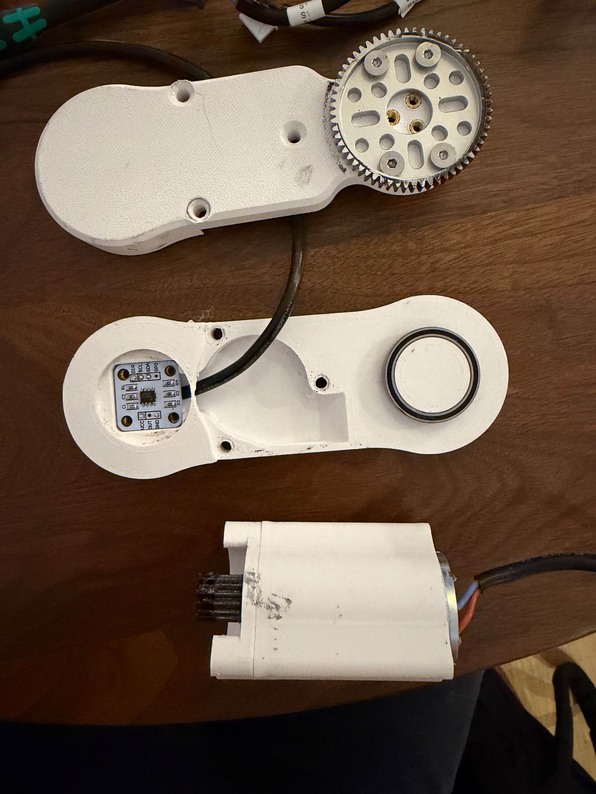
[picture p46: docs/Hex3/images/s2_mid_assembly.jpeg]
S2 Mid Assembly


#### S3 Assembly

1. Install the hub gear with the S3 gear mount.
1. Combine the spring, spring aligner, and toe together with M4x60 screws.
1. Place the toe assembly into S3. 
1. Optionally add in the toe distance time-of-flight sensor.
  - Reminder -- this is an experimental component! The TOF sensor has not been fully implemented in software at the time of writing this documentation. 
1. Close the assembly using four M4 screws (note: two are M4x30, two are M4x35).
1. Leave the rest of the assembly to a later part.

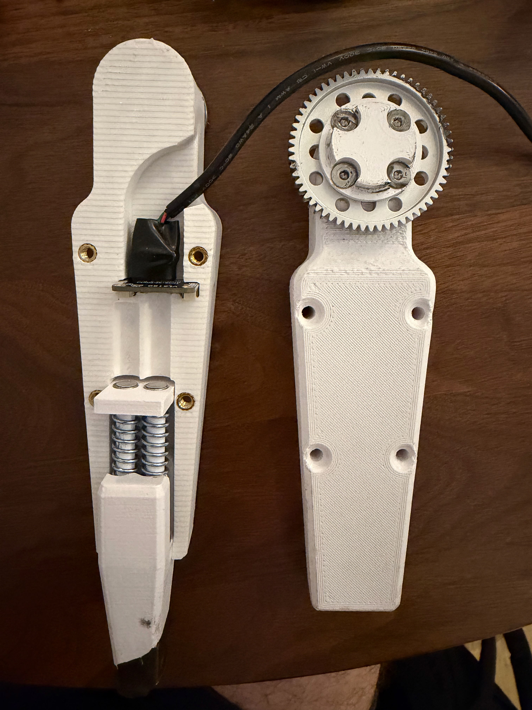
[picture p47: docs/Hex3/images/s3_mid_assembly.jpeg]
S3 Mid Assembly


#### Leg Assembly

1. Attach the S2 gear side into S1 by inserting the bearing connection piece from S2 into S1.
1. Lock the S2 gear side and S1 together by adding in the S2 motor bearing mount and S1 motor gear holder.
1. Connect the S2 bearing side and S2 motor assembly using 3 M4 screws.
1. Sandwich together the S1/S2 gear side assembly, the S3 assembly, and the S2 + motor assembly. These should all be press fit together, and locked together with 3 M4 Screws.
1. The leg assembly is complete! Follow the steps below to attach it to S0 and the base.

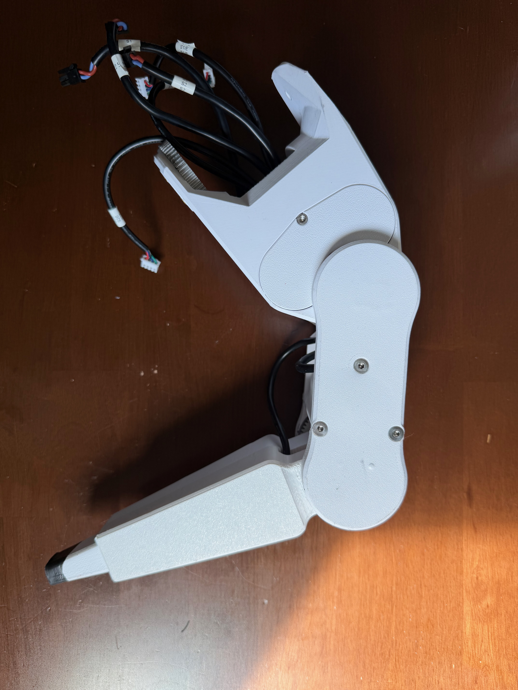
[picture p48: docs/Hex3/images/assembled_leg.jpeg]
Assembled Leg


## Base Assembly

### Part Preparation

1. Attach all M3 and M4 heatsets according to the Fusion360 Assembly.
1. Press fit all the bearings into the leg flats, and install the S1 bearing holder into each.

### Assembly

1. Attach each of the six leg PCBs to a side of the hexapod base.
1. Attach S0 using the 2-4 M4 screws on the leg flats.
1. Install the Relay and PCB mount + PCB guard from the [Electronics Assembly](electronics-setup.md).
1. Install the HDMI connector and USB connector onto the base lower.
1. Attach the base lower using M4 screws. The long M3 screws should go through the base lower, and into the S0 attachment.
1. Carefully insert the leg assemblies into the sides of the hexapod, meshing each leg's S1 hub gear with the S0 driven gear (refer to the CAD if gear alignment is unclear), and taking care to align the 3 M3 screws on the base upper and base lower.

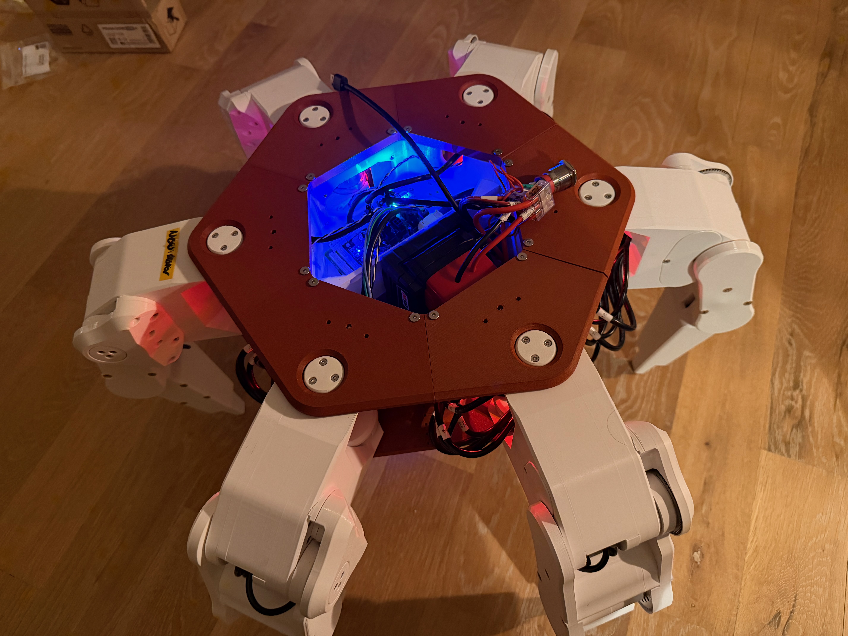
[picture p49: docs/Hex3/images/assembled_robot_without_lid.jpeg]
Assembled Robot Without Lid
    

1. Install the Raspberry Pi and wire in the power switches onto the base upper. Attach the base upper in place.
1. Assembly is complete!

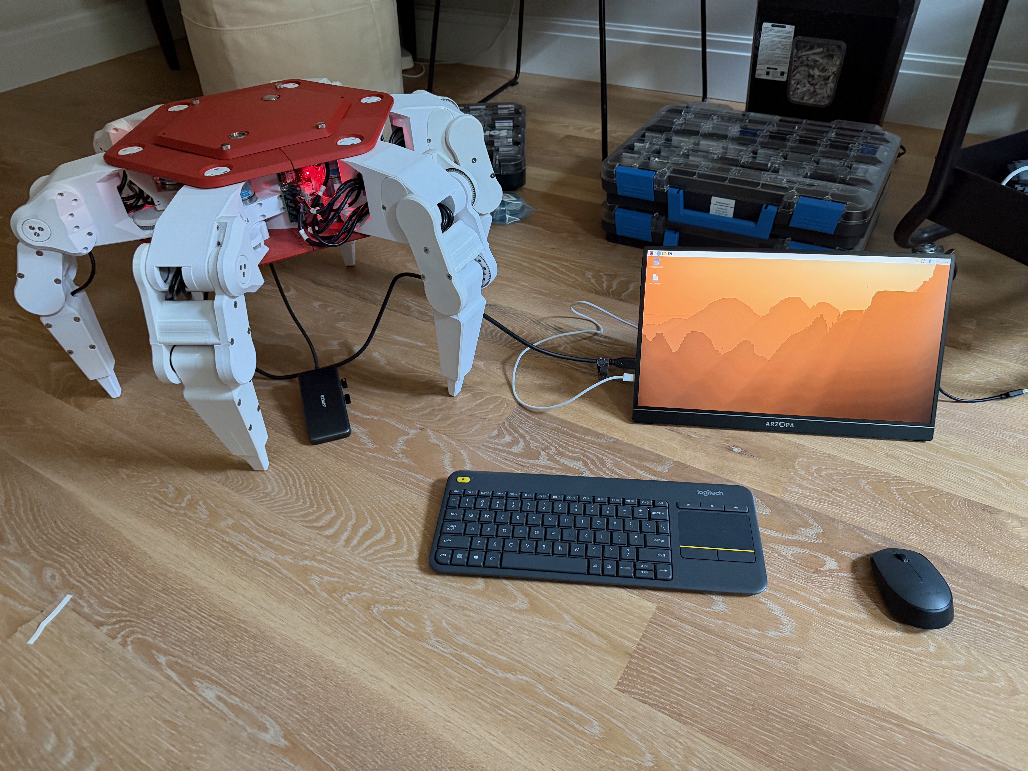
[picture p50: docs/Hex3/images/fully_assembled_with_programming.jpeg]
Fully Assembled with Programming


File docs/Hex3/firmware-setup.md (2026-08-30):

# Real-Time Firmware (Xiao RP2350)

Each of Hex3's six legs carries its own [Seeed Xiao RP2350](https://www.seeedstudio.com/Seeed-Studio-XIAO-RP2350-p-5944.html), running the firmware in `real_time/xiao_code`. It drives that leg's three axis motors and encoders, reads the toe (foot contact) sensor, and talks to the Raspberry Pi over CAN.

This page covers building, flashing, and calibrating that firmware. For wiring, see [Electronics Setup](electronics-setup.md).

## Requirements

- [VS Code](https://code.visualstudio.com/) with the [PlatformIO IDE extension](https://platformio.org/platformio-ide) (this is the recommended extension listed in the project's `.vscode/extensions.json`)
- A Seeed Xiao RP2350, connected via USB

Library dependencies (`RP2040_PWM`, `PID`, `RP2040PIO_CAN`, and the Adafruit `VL6180X` toe-sensor driver) are declared in `platformio.ini` and installed automatically by PlatformIO.

## 1. Open the Project

1. Open VS Code and install the PlatformIO IDE extension if you haven't already.
2. Use **Open Folder** and select `real_time/xiao_code`. PlatformIO will pick up `platformio.ini`, which targets the `seeed_xiao_rp2350` environment.

## 2. Create Your `user_config.hpp`

`user_config.hpp` is intentionally left out of git, since it holds per-board settings, so you need to create your own copy before the firmware will build.

1. Copy `lib/HexapodController/TEMPLATE_user_config.hpp` to `lib/HexapodController/src/user_config.hpp`.
2. Set `LEG_NUMBER` to the leg (`0`-`5`) this board is mounted on. This must be unique per leg — it also determines the board's CAN node ID (`0x100 + LEG_NUMBER` for commands from the Pi, `0x180 + LEG_NUMBER` for replies), which is how the Pi's `can` ROS2 node addresses each leg individually.
3. Set `LOG_LEVEL` and `TELEMETRY_LOGGING_SPACE` for how much serial telemetry you want while debugging.
4. Add or select a `#ifdef <YOUR_NAME> ... #endif` calibration block for this leg in `lib/HexapodController/src/config.hpp`, following the [Leg Calibration](#4-leg-calibration) steps to generate the `ZERO_POINTS` values.

## 3. Build & Upload

With the `seeed_xiao_rp2350` environment selected in PlatformIO:

1. **Build** to compile the firmware.
2. **Upload** while the Xiao is connected over USB.
3. Open the PlatformIO **Serial Monitor** at 115200 baud to confirm the board boots and prints its CAN tx/rx node IDs, along with joint position/velocity/acceleration telemetry.

## 4. Leg Calibration

1. Create a user profile in the `config.hpp` file. It should look something like:

    ```cpp
    #ifdef USER
    #define STEP_THRESHOLD 40
    #define FIFO_IDLE_THRESHOLD 100
    #define ZERO_POINTS {                    \
        {0.547631 + CALIBRATION_OFFSET_A0,   \
        -0.836020 + CALIBRATION_OFFSET_A1,  \
        2.787243 + CALIBRATION_OFFSET_A2},  \
        {0.0 + CALIBRATION_OFFSET_A0,   \
        0.0 + CALIBRATION_OFFSET_A1,  \
        0.0 + CALIBRATION_OFFSET_A2}, \
        {0.0 + CALIBRATION_OFFSET_A0,   \
        0.0 + CALIBRATION_OFFSET_A1,   \
        0.0 + CALIBRATION_OFFSET_A2},  \
        {0.0 + CALIBRATION_OFFSET_A0,  \
        0.0 + CALIBRATION_OFFSET_A1,   \
        0.0 + CALIBRATION_OFFSET_A2},  \
        {0.0 + CALIBRATION_OFFSET_A0,   \
        0.0 + CALIBRATION_OFFSET_A1,  \
        0.0 + CALIBRATION_OFFSET_A2},  \
        {0.0 + CALIBRATION_OFFSET_A0,   \
        0.0 + CALIBRATION_OFFSET_A1,  \
        0.0 + CALIBRATION_OFFSET_A2}, \
    }

    ...

    #endif
    ```

2. To calibrate your legs, set both the config values and calibration offsets to 0.0:

    ```cpp
    #define ZERO_POINTS {                    \
        {0.0 + 0.0,   \
        0.0 + 0.0,  \
        0.0 + 0.0},  \
        {0.0 + 0.0,   \
        0.0 + 0.0,  \
        0.0 + 0.0}, \
        {0.0 + 0.0,   \
        0.0 + 0.0,   \
        0.0 + 0.0},  \
        {0.0 + 0.0,  \
        0.0 + 0.0,   \
        0.0 + 0.0},  \
        {0.0 + 0.0,   \
        0.0 + 0.0,  \
        0.0 + 0.0},  \
        {0.0 + 0.0,   \
        0.0 + 0.0,  \
        0.0 + 0.0}, \
    }
    ```

3. Turn off the hexapod and move the leg to the calibration position and plug in the Xiao RP2350 on the mainboard.

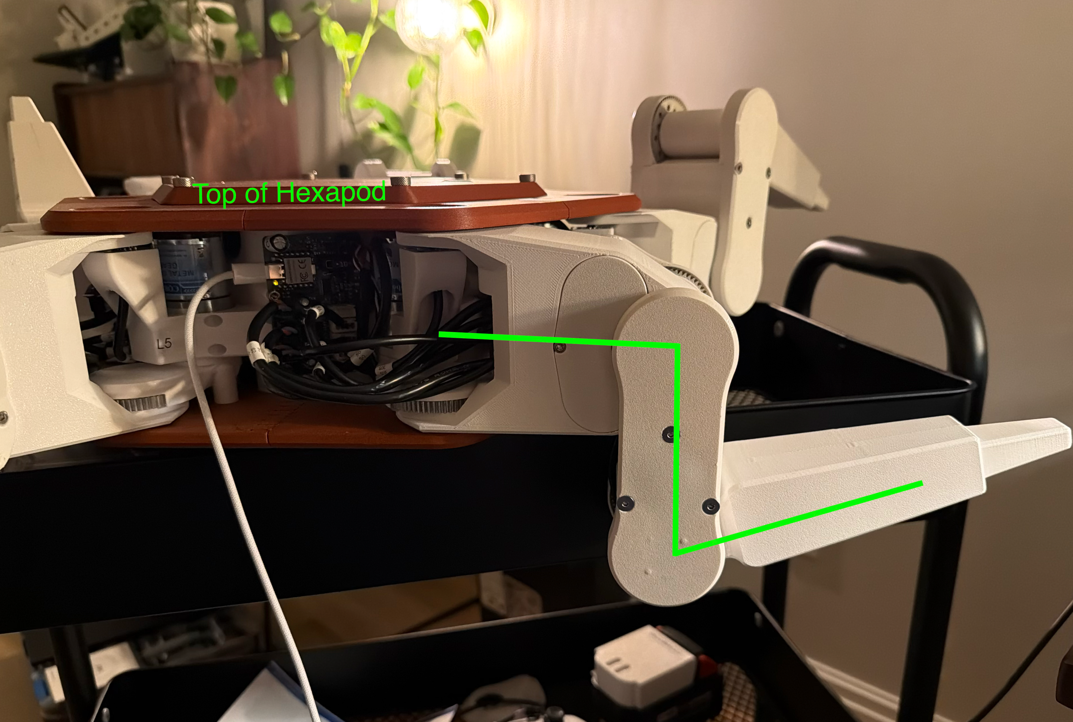
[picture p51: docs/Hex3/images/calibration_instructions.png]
calibration instructions
    

    1. S1 should be parallel with the side panel of the hexapod.
    2. S2 should be as far down as it can go. The 3 wires going into S1 must be laid out flush (the distance between S1 and S2 is exactly 1 wire diameter).
    3. S3 should be as far up as it can go (the distance between S2 and S3 is exactly 1 wire diameter).

4. Upload main.cpp and turn on the serial monitor. You should see a value like this:

    ```bash
    {"Joint": {"pos": [0.547631, -0.836020, 2.787243], "vel": [0.000049, 0.006216, 0.000052], "acc": [-0.001082, 4.619407, -0.000955], "duty": [80.000000, -80.000000, -80.000000]}, "voltage": 0.730000, "toe": 0.000000}
    ```

5. Add the code to the leg you are calibrating. For example, if we were calibrating Leg0:

    ```cpp
     #define ZERO_POINTS {                    \
        {0.547631 + CALIBRATION_OFFSET_A0,   \
        -0.836020 + CALIBRATION_OFFSET_A1,  \
         2.787243 + CALIBRATION_OFFSET_A2},  \
        {0.0 + 0.0,   \
        0.0 + 0.0,  \
        0.0 + 0.0}, \
        {0.0 + 0.0,   \
        0.0 + 0.0,   \
        0.0 + 0.0},  \
        {0.0 + 0.0,  \
        0.0 + 0.0,   \
        0.0 + 0.0},  \
        {0.0 + 0.0,   \
        0.0 + 0.0,  \
        0.0 + 0.0},  \
        {0.0 + 0.0,   \
        0.0 + 0.0,  \
        0.0 + 0.0}, \
    }
    ```

6. Upload the code to the leg and make sure it is in a standing position. (Confirm in `user_config.hpp` that you set the correct `LEG_NUMBER`).

7. Repeat for all 6 legs.

## Ad-Hoc Hardware Tests

`test/axis_test.cpp` and `test/can_test.cpp` are standalone bring-up sketches (not PlatformIO unit tests) for exercising a single axis or the CAN transceiver in isolation, independent of the full leg controller — useful when debugging one subsystem at a time.

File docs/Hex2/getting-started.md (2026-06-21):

# Setting up your Raspberry Pi 5
This section will walk you through configuring the Raspberry Pi 5 with Ubuntu, Docker, and Ros2. 

## Requirements
- Raspberry Pi 5
- Micro SD Card (64GB+ preferred).
- Micro HDMI to HDMI cable.
- USB connected keyboard.
- USB connected mouse.

## 1. Flashing the SD Card

1. [Download the Raspberry Pi imager](https://www.raspberrypi.com/software/)
2. Select `Raspberry Pi 5` as the board
3. Select `Other general-purpose OS` -> `Ubuntu` -> `Ubuntu Desktop 24.04.1 LTS (64-BIT)`
4. Select your micro SD card.
5. Click save + wait.
6. Once flashed, plug your micro SD card into your Pi and connect peripherals.

## 2. Install Docker

1. Follow the Ubuntu setup instructions on first boot. We recommend naming your profile `hexapod-<lastname>` on the system `hexapod<lastname>`. If you run into issues setting up the pi, skip the Wi-Fi connection step until the system is fully configured.
2. Follow the instructions at [Install Docker Engine on Ubuntu - Install using the `apt` repository](https://docs.docker.com/engine/install/ubuntu/#install-using-the-repository).
3. Once installed follow [Linux post-installation steps for Docker Engine](https://docs.docker.com/engine/install/linux-postinstall/) to run Docker commands without root privileges.
4. Run `apt install docker-compose`.

## 3. Download the Docker Image

1. Download the code from one of our Hex# repositories. This code does not need to live anywhere specific. Then navigate into the `non_real_time/container` directory
2. Run `./build.sh`.
3. Run `./init_dev.sh` or `./init_prod.sh` depending on interfaces required.

## 4. Run setup script to install other dependencies and create custom cronjobs

1. Navigate to your `non_real_time` directory
2. run `sudo ./setup.sh`

## 5. Edit boot file to give access to dev port

1. open file with sudo permissions
`sudo nano /boot/firmware/config.txt`
2. add this line to the bottom of the file
`dtoverlay=uart0,ctsrts`
3. be sure to save your changes!

## 6. Connect Xbox Core (Series S, X, etc) Controller

1. Controllers must have their firmware updated via the Xbox Accessories Windows app to be identified by recent Ubuntu releases.
2. Once updated, the controller can be connected via Ubuntu's bluetooth UI.

# Docker Container
This section discusses setup and use cases of our docker container
## 1. Initial setup
1. Assure docker and docker-compose are installed on your system and that docker commands can be used without privilege escalation
2. Navigate to the container directory `non_real_time/container/`
3. Build the container with ```./build.sh``` (if you are having issues with this, try pasting the .sh file contents and running from cmd line)
4. Follow the below Development Usage or Production Usage instructions depending on your use case

## 2. Development Usage 
1. Start the container with ```./init_dev.sh```
2. Create shells running inside the container with ```./new_dev_shell.sh```
3. When shutting down use ```./stop_dev.sh```

### Important Notes:
- When started with ```./init_dev.sh``` the container will be running in idle mode until stopped with ```./stop_dev.sh```
- For changes to go into effect in development the container does not need to be rebuilt after the initial build, but to move to production, it will be
- Make sure all code that is intended to run during container operation resides in the src directory
- Make sure any system packages or python packages installed get added to ```setup/system-requirements.txt``` or ```setup/python-requirements.txt``` for those packages to be included into the container at the next build
- For help with running or launching our ros2 nodes and packages please see the [Ros2 Packages and Nodes](https://github.com/ManufacturedMotion/Hexapod/wiki/Useful-Commands#ros2-packages--nodes) section of our Useful Commands wiki

## 3. Production Usage
1. Start the production container with ```./init_prod.sh```

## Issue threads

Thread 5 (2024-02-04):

Header File with Configuration

Diacoba1, 2024-02-04:
Write code that takes in an offsets.h file and can use each of our offsets in the code. Should be flexible enough that we just need to specify whose bot it is, and the rest is abstracted away.

DillonKane, 2024-02-05:
First rev done. Could not dynamically create an array of axis objects and then use a for loop to define motor pins, etc. Instead that is hard coded for now -- this was what I was trying:

```
Axis axes[6][3];
  for (uint8_t i = 0; i < 6; i++) {
    for (uint8_t j = 0; j < 3; j++) {
        axes[i][j] = Axis(pwm_pins[i][j], min_pos[i][j] * scale_fact[i][j], max_pos[i][j] * scale_fact[i][j]);
    }
  }
```
This was not correctly meshing with the servos

Diacoba1, 2024-02-29:
- [ ] PWM pins defined per user
- [ ] Swap zero points for L1 & L2 for Danny and Zack
- [ ] Move `#define USER DILLON` to before the includes of the Arduino file

DillonKane, 2024-02-29:
https://github.com/ManufacturedMotion/HexapodController/pull/2

Closed 2024-02-29.

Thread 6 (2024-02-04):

Update the Base to allow for Battery removal

Diacoba1, 2024-02-04:
Modify the base to allow the battery to be slid in and out on the side with the custom fit brackets. It should be held in place with the lid mounting piece that has two screws.

Diacoba1, 2024-02-06:
#10

Closed 2024-02-06.

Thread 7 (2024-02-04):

Update the S1 Mounting

Diacoba1, 2024-02-04:
Update the S1 Mounting to:

- Allow for 4 screws to be used
- Have the chamfer on the correct side
- Have the mounting screws in the correct place

Closed 2024-02-12.

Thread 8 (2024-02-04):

Position and Orientation of Robot

Diacoba1, 2024-02-04:
From ChatGPT:
I have a robot with three legs. With it standing on those three legs, I want it to calculate the position and orientation of the center of the robot. How can I do this?

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

Diacoba1, 2024-02-29:
Decided coordinate system, in progress. Need to figure out how Yaw impacts X and Y

Closed 2024-04-04.

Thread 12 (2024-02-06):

Update Servo Mounts

DillonKane, 2024-02-06:
update screw spacing on all servo mounts so all 4 screws can be used

Diacoba1, 2024-02-12:
Cleared assignees -- we should only assign to one person so we know who is tackling it

Diacoba1, 2024-02-12:
I have already updated S1, and S2. The final change needs to be done for S3. But we should lump it in with the toe fixes

Diacoba1, 2024-02-13:
- [ ] Update S1 Motor mount to not have an overhang
- [ ] Check out S3 spacing

Closed 2024-02-14.

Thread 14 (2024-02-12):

Update S3 Toe Mount

Diacoba1, 2024-02-12:
Update S3 so the toe rod is held in place, and the limit switch cover so we don't need to cut away parts of S3

Diacoba1, 2024-03-15:
Dillon test this

Closed 2024-03-28.

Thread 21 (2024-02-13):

Raspberry Pi Passthrough

Diacoba1, 2024-02-13:
- [ ] A pass through using serial to send commands to the Teensy
- [ ] SSH into the raspberry pi wirelessly, run a script that gives us a serial monitor

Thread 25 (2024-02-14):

Design the Lid

Diacoba1, 2024-02-14:
The lid should meet the following requirements:

- [x] Be able to be printed in two colors without the need of an AMS
- [x] Have the Manufactured Motion Logo Printed on the Lid
- [x] Securely attach to the base with as few screws as possible (max 6)
- [x] Attach with screws standard to the rest of the bot
- [x] Provide access to the switch
- [x] Cover cables without significantly increasing height or restricting range of motion

Closed 2024-02-28.

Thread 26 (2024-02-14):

Redesign S3

Diacoba1, 2024-02-14:
Redesign S3 to address the following issues/concerns:

- [x] The zip tie mounts in the cable channel do not function properly
- [x] The servo can only use 2/4 screws
- [x] The motor connector piece can easily be overtightened, cracking the piece
- [x] The part is not optimized for 3D printing -- significant supports are needed and they are hard to remove

Diacoba1, 2024-04-03:
Just need to upload the new files to Github

Closed 2024-04-14.

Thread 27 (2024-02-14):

PCB Second Generation

Diacoba1, 2024-02-14:
Making this issue to track future improvements to the PCB:

- [x] **Convert the PCB to working with a Raspberry Pi 5 instead of a Pi Zero W**
- [x] PCB should attach to the Raspberry Pi (breakout attachment)
- [x] Change the motor connector order so it goes 123 instead of 213
- [x] Change the switch connector to be an XT-30 instead of two vias
- [x] Improve the readability of the silkscreen once connectors are attached
- [x] ~Add in physical low voltage cutoff~ Dropping this in favor of a way to read the voltage and get those values on the pi.
- [x] ~Add in Touchscreen for current status~ USB + HDMI, no physical connections required
- [x] Lever to switch between control modes (redesign not required) (Or dipswitches on the board?)
- [x] ~Big button for regular and autonomous~ Deprecating in favor of the touch screen
- [x] ~1-3 LEDs for status indication~ Deprecating in favor of the touch screen
- [x] Add in the Manufactured Motion logo to the back of the PCB
- [x] ~Connections for Lidar~ -- should be USB

Diacoba1, 2024-06-04:
#83 Began working on some of these points

Diacoba1, 2024-06-25:
#97

Closed 2024-06-25.

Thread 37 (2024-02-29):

Measure from actual center of bot to S1 for each leg

Diacoba1, 2024-02-29:
Measure from actual center of bot to S1 for each leg. Get the X and Y offsets.

- With battery on the bottom, L/R is X, Up/Down is Y.
- Half the values should be negative

3 | 4
2 | 5
1 | 6

Diacoba1, 2024-03-09:
#45

Closed 2024-03-09.

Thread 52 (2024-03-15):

Update Example File

Diacoba1, 2024-03-15:
- [x] Case 0 is a break
- [x] Case 1-6 controls that specific legs IK
- [x] Case 7 move to all zeros
- [x] Each case should have its own scanf

Diacoba1, 2024-03-23:
https://github.com/ManufacturedMotion/HexapodController/pull/4

Closed 2024-03-23.

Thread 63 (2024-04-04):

WebServer Enhancements

Diacoba1, 2024-04-04:
- [x] Swap from Threads to multiprocessing (true multi-threading) on the Pi
- [x] Fix the read serial action so it is properly sent to the webpage

Diacoba1, 2024-04-04:
#65

Closed 2024-04-04.

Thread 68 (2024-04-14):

Raspberry Pi as a WAP

Diacoba1, 2024-04-14:
- [x] If there is a network available, use that network
- [x] If there is not, launch a soft-access point

Diacoba1, 2024-06-21:
A lot of these issues go away with the transition to a full pi running Ubuntu, so closing out

Closed 2024-06-21.

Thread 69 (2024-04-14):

Raspberry Pi WebServer does not function w/o hard access point

Diacoba1, 2024-04-14:
- [ ] Flask WebServer fails without an internet connection -- why?
- [ ] Logo is not rendered as it is hosted on Github

Diacoba1, 2024-06-25:
Not an issue with running Ubuntu, we can have it act as a bridge between the network and the user

Closed 2024-06-25.

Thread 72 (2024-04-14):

Leg Breakout Boards

Diacoba1, 2024-04-14:
Instead of needing each leg to have a wiring harness, we should design a small PCB to mount to each S0.

- [x] Connectors for the data for each servo
- [x] Common ground and 5v lines
- [x] Screw mounting

Diacoba1, 2024-06-21:
#88

Closed 2024-06-21.

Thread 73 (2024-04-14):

Hexapod Gen 2

Iacobacci, 2024-04-14:
- [x] **Redesign the hexapod base to function with the Gen 2 PCB**
- [x] Significantly larger magnets so the base could be lifted up from the magnets
- [x] Adjust the logo on the lid so it always is at the back of the hexapod
- [x] Modify S1 to be able to fit connectors through the cable routing hole

Iacobacci, 2024-08-22:
#107

Closed 2024-08-22.

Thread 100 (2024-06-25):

Test the mk2 main board

Iacobacci, 2024-06-25:
Confirm the following works:

- [x] Voltage divider outputs a voltage within the acceptable range for the pins
- [x] pi can control LED ring
- [x] pi can talk to teensy
- [x] pi can control fan
- [x] voltage divider sends correct value to teensy (battery reading)
- [x] new board can control servos

DillonKane, 2024-08-24:
can measure temp for fan control logic with "sudo vcgencmd measure_temp"

DillonKane, 2024-08-24:
voltage divider needs to be multiplied by offset of 0.01606 to get correct reading

DillonKane, 2024-08-31:
voltage divider sends vdd of 2.45 with battery vdd of 12.3V

zschwid, 2024-10-13:
Can we get a status update here?

DillonKane, 2024-11-19:
Pi can control LED ring if jumper connector is used for LED signal wire. Jumper connects SIG to Pi pin MOSI SCLK0.

Will be addressed with PCB redesign

Closed 2024-11-19.

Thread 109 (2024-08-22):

"Final" CAD Revisions

Iacobacci, 2024-08-22:
- [x] Update S2 Magnets
- [x] S3 Revisions
- [x] Modify lid to cover bot more
- [x] Expand buffer around battery
- [x] Tighter tolerance on brace
- [x] Chamfer brace corners
- [x] Make middle lid support wider
- [x] Cable management

Iacobacci, 2024-08-27:
#111

Closed 2024-08-27.

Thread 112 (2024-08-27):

Mechanical BOM

Iacobacci, 2024-08-27:
Put together a BOM of all the mechanical parts (3D printed parts, screws, bearings, magnets, etc) needed to assemble the hexapod

Iacobacci, 2025-01-20:
Rough draft done in #152 , closing out until project is complete

Closed 2025-01-20.

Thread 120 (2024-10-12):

Assess walking robot simulation frameworks

zschwid, 2024-10-12:
Determine a good framework to use for simulation of the hexapod for RL training

Iacobacci, 2025-02-14:
Switching from Gazebo to IsaacGym

Closed 2025-02-14.

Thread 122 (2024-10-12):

Model has inconsistencies with small motions

zschwid, 2024-10-12:
Very small steps can lead to commanding positions that the hexapod mechanically cannot keep up with. Rework model to account for this case

Closed 2025-02-14.

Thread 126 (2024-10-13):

Voltage drops momentarily when all motors make collision, causing the RPi to shutdown due to undervoltage

zschwid, 2024-10-13:
Fixes to try:
- Add bulk / decoupling capacitance
- Bigger buck converter

Iacobacci, 2024-11-14:
We are going to remediate this with a PCB re-design to run the servos independently off the battery, with the Buck converter being dedicated to the Pi, Fan, LEDs, and other peripherals. Tracked In #130

Closed 2024-11-14.

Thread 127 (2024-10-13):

CAD Changes

zschwid, 2024-10-13:
- [x] S0 PCB mounting
- [x] Bracket (Brace)
- [x] Lid fixes
- [x] Upload archive to git

Closed 2024-11-06.

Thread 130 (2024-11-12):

PCB Redesign

Iacobacci, 2024-11-12:
Redesign the PCB to isolate the servo power and the 5V regulated power.

Schematic:
- [x] Validate the servos can run directly off a 7.4v battery (and up to the maximum charge).
- [x] Run the servos off 7.4v (battery voltage) rather than 5v from the buck converter.
- [x] Add a replaceable fuse (40A) off the battery as a maximum draw.
- [x] ~Switch the Dip Switch to be through hole rather than surface mount.~ Remove the dip switches
- [x] Update Pi power switch to use Pins 9 and 11 (GND, GPIO 17)

Board:
- [x] New board layout
- [x] Order board via JLC/PCBway

Closed 2024-11-26.

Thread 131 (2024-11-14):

Raspberry Pi Soft Shutdown

Iacobacci, 2024-11-14:
The raspberry pi should trigger a soft shutdown when the appropriate button is pressed. This will prevent the SD card from corrupting, which is caused by improper shutdowns.

Closed 2024-11-24.

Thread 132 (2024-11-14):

Xbox Controller to Single Leg Control

Iacobacci, 2024-11-14:
To test the integration of the system, limited by the Hexapod's power distribution, I think we should prioritize testing with one leg and the Xbox Controller.

Test would require:

- [x] Controller to sync correctly to the Pi
- [x] A script on the pi to parse controller inputs
- [x] The pi to send those commands over serial
- [x] The Teensy to be able to process those commands
- [x] The teensy to issue instructions to the leg.

We have most of these pieces functioning independently, but they are not fully functioning together.

DillonKane, 2025-03-02:
Done as per: https://github.com/ManufacturedMotion/Hexapod/pull/186 which allows controller to send preset commands or walk instructions over serial

Closed 2025-03-02.

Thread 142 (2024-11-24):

Test PCB Rev 2.0

Iacobacci, 2024-11-24:
Test:

- [x] Confirm buck converter voltage
- [x] Confirm all 18 servos could function without platform instability
- [x] Test Pi Powerswitch
- [x] LED functionality

Closed 2024-12-28.

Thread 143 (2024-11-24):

Increase S0/S1 Wire Clearance

Iacobacci, 2024-11-24:
- Increase clearance for wires for S0/S1 so the cables no longer get caught

Closed 2024-12-29.

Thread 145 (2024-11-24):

Dead Code Cleanup

Iacobacci, 2024-11-24:
Ensure deprecated code is removed. Necessary after the Fall Surge

DillonKane, 2025-01-13:
I think we caught a lot of this during the first pass, but here is what I found this time around.

Undefined functions:

- [hexapod.hpp firstStepSetup](https://github.com/ManufacturedMotion/Hexapod/blob/main/mk2/code/real_time/teensy_code/lib/HexapodController/src/hexapod.hpp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)
- [leg.hpp linearMove](https://github.com/ManufacturedMotion/Hexapod/blob/main/mk2/code/real_time/teensy_code/lib/HexapodController/src/leg.hpp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)
- [leg.hpp runLegSpeed](https://github.com/ManufacturedMotion/Hexapod/blob/main/mk2/code/real_time/teensy_code/lib/HexapodController/src/leg.hpp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)
- [leg.hpp setLeg](https://github.com/ManufacturedMotion/Hexapod/blob/main/mk2/code/real_time/teensy_code/lib/HexapodController/src/leg.hpp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)
- [leg.hpp _linearMovement](https://github.com/ManufacturedMotion/Hexapod/blob/main/mk2/code/real_time/teensy_code/lib/HexapodController/src/leg.hpp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)
- [position.hpp addPos](https://github.com/ManufacturedMotion/Hexapod/blob/main/mk2/code/real_time/teensy_code/lib/HexapodController/src/position.hpp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)
- [position.hpp subtractPos](https://github.com/ManufacturedMotion/Hexapod/blob/main/mk2/code/real_time/teensy_code/lib/HexapodController/src/position.hpp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)
- [position.hpp distanceFromOrigin](https://github.com/ManufacturedMotion/Hexapod/blob/main/mk2/code/real_time/teensy_code/lib/HexapodController/src/position.hpp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)
- [three_by_matrices.hpp add](https://github.com/ManufacturedMotion/Hexapod/blob/main/mk2/code/real_time/teensy_code/lib/HexapodController/src/three_by_matrices.hpp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)

There is also this file I think we no longer need to track since we have our config.hpp with the same information
https://github.com/ManufacturedMotion/Hexapod/blob/main/mk2/code/offsets.md

@zschwid since you defined most of these functions can you give a quick look here and let me know which we will populate and which to remove? I can't remember if we discussed this in Nov and don't want to cut anything we will fill out

DillonKane, 2025-02-02:
https://github.com/ManufacturedMotion/Hexapod/pull/154

Closed 2025-02-02.

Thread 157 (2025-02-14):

Battery Voltage Measurements

Iacobacci, 2025-02-14:
- [x] Have the battery voltage stored in JSON format
- [x] Send the battery voltage to the pi every time the voltage changes a certain value
- [x] On the pi side convert the battery voltage to a percentage -> likely using a lookup table

Flow:
Teensy has the voltage divided value on a pin -> Teensy converts the divided value into a usable measure and applies noise filtering -> Teensy sends this value in a JSON blob over serial -> "Teensy" ROS node on pi is connected to UART/Serial and picks up that value -> "Teensy" Node publishes that to a topic -->  node on the Pi is listening, picks up that value, and converts it to a percentage.

DillonKane, 2025-02-20:
to fix blocking issue we can use polling counters: think of embedded course. static var for counter and increment every loop instead of using a while loop.

DillonKane, 2025-02-22:
when working on pi side we want a soft warning at 3.5V per cell and hard cutoff at 3.3V

DillonKane, 2025-02-22:
first two bullets accomplished with these updates: https://github.com/ManufacturedMotion/Hexapod/pull/178

DillonKane, 2025-04-17:
lithium ion open cell voltage

Closed 2025-06-29.

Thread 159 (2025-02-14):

JSON Parsing for 18 Leg Position Setting

Iacobacci, 2025-02-14:
G2 code change in main.cpp

JSON Parsing for 18 Leg Position Setting -- Would need to use Arduino JSON Parsing

This command would always send a key value pair for ALL 18 motors. It can call move to pos at speed underneath to do actual movements

```
{
    "L0S1": 0,
    ...
    "L5S3": -3.14
}
```

DillonKane, 2025-02-16:
example command:

```
G2 {"L0S1":0,"L0S2":0,"L0S3":0,"L1S1":0,"L1S2":0,"L1S3":0,"L2S1":0,"L2S2":0,"L2S3":0,"L3S1":0,"L3S2":0,"L3S3":0,"L4S1":0,"L4S2":0,"L4S3":0,"L5S1":0,"L5S2":0,"L5S3":0}
```

DillonKane, 2025-02-16:
https://github.com/ManufacturedMotion/Hexapod/pull/166

Closed 2025-02-20.

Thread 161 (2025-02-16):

- not sure if i want to do this or send unique val for no measure

DillonKane, 2025-02-16:
```
        //todo - not sure if i want to do this or send unique val for no measure
```

In file mk2/code/real_time/teensy_code/lib/HexapodController/src/voltage_monitor.cpp
undefined

DillonKane, 2025-02-16:
accidentally made this from inside vscode

Closed 2025-02-16.

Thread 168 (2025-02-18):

Containerized LEDs

Iacobacci, 2025-02-18:
Setup the LEDs to work within the docker container, rather than requiring additional configuration at startup. There may still be some configuration required to get the LEDs accessible to the docker container, but all the python packages installations should be handled by the container. (python-requirements.txt)

Iacobacci, 2025-03-04:
#188 Since there was functionality missing (joystick) in #187

Closed 2025-03-04.

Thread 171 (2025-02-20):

Strafing Twist -> Walk Setup Functions

Iacobacci, 2025-02-20:
Create a new package `gait` + node `teensy_gait` that takes in twist strafe values and converts it to the hexapod.walk_setup on the teensy.

- Subscribe to the /cmd_vel topic
- Convert this to the format needed for the teensy gait
- Publish the formatted command to the /to_teensy topic

Right Stick X-Axis: Linear +/- X (Holonomic Mode (Strafing) -- Walking in a direction without turning in that direction)
Right Stick Y-Axis: Linear +/- Y (Holonomic Mode (Strafing) -- Walking in a direction without turning in that direction)

Reference (but do better): mk2/code/non_real_time/container/src/ros2_ws/src/gait_node/gait_node/gait.py --  note: this is untested and may not work.

Existing Teensy Node (requires rework): https://github.com/ManufacturedMotion/Hexapod/blob/main/mk2/code/non_real_time/container/src/ros2_ws/src/teensy_node/teensy_node/uart_teensy.py

Change these:

```
 self.publisher_ = self.create_publisher(String, '/teensy_receive', 10)
 self.subscriber = self.create_subscription(String,'teensy_send',self.send_to_teensy,10)
```

```
 self.publisher_ = self.create_publisher(String, '/from_teensy', 10)
 self.subscriber = self.create_subscription(String,'/to_teensy',self.send_to_teensy,10)
```

DillonKane, 2025-02-27:
```
ros2 run teensy_node teensy_node

ros2 run gait teensy_gait
```

DillonKane, 2025-03-02:
https://github.com/ManufacturedMotion/Hexapod/pull/186

Closed 2025-03-02.

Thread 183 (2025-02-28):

Teensy gait account for yaw

zschwid, 2025-02-28:
- [ ] Add new (optional) argument to walkSetup called yaw to indicate the yaw that should be completed during the walk
- [ ] Update gait to account for changes in Yaw

DillonKane, 2025-03-01:
I think we also want walk setup to account for roll/pitch. Right now they are not consumed

zschwid, 2025-04-17:
Roll and pitch require no steps so will be handled by linearMove, which is already in place.

zschwid, 2025-04-17:
May change all walkSetup commands to linearMoveSetup commands instead which would account for all 6 axis motion with steps

zschwid, 2025-05-05:
In progress, troubleshooting returning to neutral.

Closed 2025-05-17.

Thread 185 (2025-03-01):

Add button mapping for Speed to teensy gait

DillonKane, 2025-03-01:

DillonKane, 2025-03-07:
send speed as part of MV json. speed will scale with how far joystick is pushed. Can also then tweak step size in gait node to walk with larger steps.

faster speed will prevent queue build up

Closed 2025-03-08.

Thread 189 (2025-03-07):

Option to power down all servos

DillonKane, 2025-03-07:

DillonKane, 2025-03-07:
maybe make this what the y button does and we can remove starfish?

zschwid, 2025-05-17:
Complicated to do with Teensy compatible PWMServo library, not worth the effort / time commitment at this point in development cycle

Closed 2025-05-17.

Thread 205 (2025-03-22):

new json/gcode command

DillonKane, 2025-03-22:
"TUNE" key for json

add option to tune only one motor at a time by providing the leg, motor and position

DillonKane, 2025-03-22:
make sure to also add instruction to wiki page

DillonKane, 2025-03-23:
https://github.com/ManufacturedMotion/Hexapod/pull/213

Closed 2025-03-23.

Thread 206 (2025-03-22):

parsing safety nets

DillonKane, 2025-03-22:
ex:
```
        else if (token[0] == 'L') {
            uint8_t L_end = token.find('S');
            uint8_t leg = std::stoi(token.substr(1, L_end - 1));
            uint8_t axis = std::stoi(token.substr(L_end + 1, 1)) - 1;
            double pos = std::stod(token.substr(L_end + 2));
            if ((leg >= 0 && leg < NUM_LEGS) && (axis >= 0 && axis < NUM_AXES_PER_LEG)) {
                _leg_positions[leg][axis] = pos;
            }
        }
```
should not move motors when given L3 0 0 0 command

probably just return if S is missing from key
```
    if (L_end == std::string::npos) {
        return;  // or use 'continue;' if this is inside a loop
    }
```

DillonKane, 2025-03-23:
https://github.com/ManufacturedMotion/Hexapod/pull/213

Closed 2025-03-23.

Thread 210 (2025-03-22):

move images/cad/pcb/etc. to another spot?

DillonKane, 2025-03-22:
should we move the cad, pcbs, images, etc. (pretty much anything that is not code) to another location? We don't need access to these files on the pi or teensy. Any time these files are touched it slows down the git pull process for me and it will consume extra memory on the pi.

Maybe instead of moving everything else, we can move Mk1 / Mk2 into submodules? Then on the pi we only need to clone the submodule and not the full repo?

DillonKane, 2025-03-22:
I am thinking of some submodule options:
* `mk1/code`, `mk2/code`
  * would have teensy and pi code in same repo
* `mk1/code/non_real_time`, `mk2/code/non_real_time`
  * would only have pi code
* `mk1/code/real_time`, `mk2/code/rreal_time`
  * would only have teensy code
* or a combination of above:   `mk1/code/real_time`, `mk2/code/rreal_time`, & `mk1/code/non_real_time`, `mk2/code/non_real_time`
  * user can clone non_real_time on pi for remote dev and minimal overhead. Can also clone teensy code to a separate space for teensy dev with no extra overhead

Closed 2025-05-27.

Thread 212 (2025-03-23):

change DEBUG to DEBUG_LEVEL

DillonKane, 2025-03-23:
instead of 1 or 0 give more levels for debug printing

i.e.
0 - no debug
1 - print serial msgs
2 - print leg movement calculations, etc.

DillonKane, 2025-03-23:
make serial class with function that take msg and min log level.

ex: <class function>.log(<msg>, 3)
only logs the message if the DEBUG_LEVEL >= 3 in user_config

zschwid, 2025-04-13:
Use preprocessor to handle debug levels so that debug commands not in use get compiled out

DillonKane, 2025-04-22:
WIP: https://github.com/ManufacturedMotion/Hexapod/tree/serial_logging

I have most of the logging handled by the preprocessor on above branch but hit a snag. The current parser code for json/gcode/serial commands requires a pointer to our hexapod instance to be passed around. The only alternative to this I am thinking of now is to have the code to execute json/gcode commands live inside of Hexapod.cpp. I don't really like this though, I want to try and keep the parsing in separate source files

DillonKane, 2025-04-25:
remove serialHandler and just use serial.print

kill gcode support!!

DillonKane, 2025-05-04:
https://github.com/ManufacturedMotion/Hexapod/pull/231

Closed 2025-05-04.

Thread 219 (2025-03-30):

Teensy use and publish toe limit switch state changes to RPi

zschwid, 2025-03-30:
First pass: publish the toe limit switch state changes up to RPi

Iacobacci, 2025-07-17:
We removed the limit switches from the current design, so closing out this issue as not planned

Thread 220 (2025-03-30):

Teensy use toe limit switch states in gait

zschwid, 2025-03-30:
Instead of lifting and putting legs down a static amount, utilize the toe limit switches to dynamically adjust how far legs are put down during a step.

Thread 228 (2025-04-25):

reorganize library folder

DillonKane, 2025-04-25:

DillonKane, 2025-04-25:
when doing this we can pull things out of the hexapod class where necessary. I.E. voltage sensor does not need an instance in hexapod.cpp

in main.cpp
hexapod.voltageSensor.checkVoltage()  ->  voltageSensor.checkVoltage()

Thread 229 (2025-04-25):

All hexapod movements to return move time

DillonKane, 2025-04-25:
Zack to update hexapod.cpp so all movements return a time

Dillon to update serial comms after so Pi gets knowledge of times. use this for command timing spacing

DillonKane, 2025-05-05:
enqueRapidMove and WalkSetup return the times. send these back to the pi to be used for delay before next send

DillonKane, 2025-05-07:
```
[teensy_node-3] [INFO] [1746579720.404851495] [teensy_node]: TeensyNode received {"MOVE_TIME":416} from teensy
[teensy_node-3] [INFO] [1746579923.193385088] [teensy_node]: TeensyNode writing to teensy serial: {"MV": "WLK", "X": 45.097, "Y": -145.391, "Z": 0, "ROLL": 0.0, "PTCH": 0.0, "YAW": 0.0, "SPD": 270.0}
[teensy_node-3] [INFO] [1746579924.204767718] [teensy_node]: TeensyNode received {"MOVE_TIME":562} from teensy
[teensy_node-3] [INFO] [1746579924.393246604] [teensy_node]: TeensyNode writing to teensy serial: {"MV": "WLK", "X": -93.253, "Y": -155.737, "Z": 0, "ROLL": 0.0, "PTCH": 0.0, "YAW": 0.0, "SPD": 286.73}
[teensy_node-3] [INFO] [1746579925.404693853] [teensy_node]: TeensyNode received {"MOVE_TIME":632} from teensy
[teensy_node-3] [INFO] [1746579925.593209793] [teensy_node]: TeensyNode writing to teensy serial: {"MV": "WLK", "X": -96.24, "Y": 156.152, "Z": 0, "ROLL": 0.0, "PTCH": 0.0, "YAW": 0.0, "SPD": 288.19}
[teensy_node-3] [INFO] [1746579926.604831088] [teensy_node]: TeensyNode received {"MOVE_TIME":1729} from teensy
[teensy_node-3] [INFO] [1746579926.793208748] [teensy_node]: TeensyNode writing to teensy serial: {"MV": "WLK", "X": 5.326, "Y": 136.0, "Z": 0, "ROLL": 0.0, "PTCH": 0.0, "YAW": 0.0, "SPD": 264.21}
[teensy_node-3] [INFO] [1746579927.804765532] [teensy_node]: TeensyNode received {"MOVE_TIME":514} from teensy
[teensy_node-3] [INFO] [1746579927.993193690] [teensy_node]: TeensyNode writing to teensy serial: {"MV": "WLK", "X": 3.993, "Y": 54.663, "Z": 0, "ROLL": 0.0, "PTCH": 0.0, "YAW": 0.0, "SPD": 250}
[teensy_node-3] [INFO] [1746579929.004733462] [teensy_node]: TeensyNode received {"MOVE_TIME":219} from teensy
[teensy_node-3] [INFO] [1746579929.193196099] [teensy_node]: TeensyNode writing to teensy serial: {"MV": "WLK", "X": 88.314, "Y": 0.0, "Z": 0, "ROLL": 0.0, "PTCH": 0.0, "YAW": 0.0, "SPD": 250}
[teensy_node-3] [INFO] [1746579930.204819695] [teensy_node]: TeensyNode received {"MOVE_TIME":352} from teensy
[teensy_node-3] [INFO] [1746579930.393195681] [teensy_node]: TeensyNode writing to teensy serial: {"MV": "WLK", "X": 72.372, "Y": 0.0, "Z": 0, "ROLL": 0.0, "PTCH": 0.0, "YAW": 0.0, "SPD": 250}
[teensy_node-3] [INFO] [1746579931.404801247] [teensy_node]: TeensyNode received {"MOVE_TIME":289} from teensy
[teensy_node-3] [INFO] [1746579931.593315696] [teensy_node]: TeensyNode writing to teensy serial: {"MV": "WLK", "X": 0.0, "Y": -31.302, "Z": 0, "ROLL": 0.0, "PTCH": 0.0, "YAW": 0.0, "SPD": 250}
[teensy_node-3] [INFO] [1746579932.604832306] [teensy_node]: TeensyNode received {"MOVE_TIME":125} from teensy
[teensy_node-3] [INFO] [1746579933.593194917] [teensy_node]: TeensyNode writing to teensy serial: {"MV": "WLK", "X": 0.0, "Y": -180.031, "Z": 0, "ROLL": 0.0, "PTCH": 0.0, "YAW": 0.0, "SPD": 285.62}
[teensy_node-3] [INFO] [1746579934.604872788] [teensy_node]: TeensyNode received {"MOVE_TIME":629} from teensy
[teensy_node-3] [INFO] [1746579934.793219564] [teensy_node]: TeensyNode writing to teensy serial: {"MV": "WLK", "X": -176.0, "Y": 47.375, "Z": 0, "ROLL": 0.0, "PTCH": 0.0, "YAW": 0.0, "SPD": 287.29}
[teensy_node-3] [INFO] [1746579935.804824257] [teensy_node]: TeensyNode received {"MOVE_TIME":633} from teensy
[teensy_node-3] [INFO] [1746579935.993250587] [teensy_node]: TeensyNode writing to teensy serial: {"MV": "WLK", "X": 97.243, "Y": 152.188, "Z": 0, "ROLL": 0.0, "PTCH": 0.0, "YAW": 0.0, "SPD": 286.04}
[teensy_node-3] [INFO] [1746579937.004038354] [teensy_node]: TeensyNode received {"MOVE_TIME":1701} from teensy
[teensy_node-3] [INFO] [1746579946.193343317] [teensy_node]: TeensyNode writing to teensy serial: {"MV": "WLK", "X": 132.329, "Y": -60.921, "Z": 0, "ROLL": 0.0, "PTCH": 0.0, "YAW": 0.0, "SPD": 267.42}
[teensy_node-3] [INFO] [1746579947.204978353] [teensy_node]: TeensyNode received {"MOVE_TIME":1750} from teensy
[teensy_node-3] [INFO] [1746579947.393282625] [teensy_node]: TeensyNode writing to teensy serial: {"MV": "WLK", "X": 32.563, "Y": 0.0, "Z": 0, "ROLL": 0.0, "PTCH": 0.0, "YAW": 0.0, "SPD": 250}
[teensy_node-3] [INFO] [1746579948.404808428] [teensy_node]: TeensyNode received {"MOVE_TIME":130} from teensy
[teensy_node-3] [INFO] [1746579958.793256351] [teensy_node]: TeensyNode writing to teensy serial: {"MV": "WLK", "X": -101.07, "Y": -19.746, "Z": 0, "ROLL": 0.0, "PTCH": 0.0, "YAW": 0.0, "SPD": 256.84}
[teensy_node-3] [INFO] [1746579959.804694887] [teensy_node]: TeensyNode received {"MOVE_TIME":400} from teensy
[teensy_node-3] [INFO] [1746579959.993268568] [teensy_node]: TeensyNode writing to teensy serial: {"MV": "WLK", "X": -156.0, "Y": -39.031, "Z": 0, "ROLL": 0.0, "PTCH": 0.0, "YAW": 0.0, "SPD": 273.93}
[teensy_node-3] [INFO] [1746579961.005039375] [teensy_node]: TeensyNode received {"MOVE_TIME":586} from teensy
[teensy_node-3] [INFO] [1746579961.193264179] [teensy_node]: TeensyNode writing to teensy serial: {"MV": "WLK", "X": -152.0, "Y": 37.853, "Z": 0, "ROLL": 0.0, "PTCH": 0.0, "YAW": 0.0, "SPD": 271.94}
[teensy_node-3] [INFO] [1746579962.204649583] [teensy_node]: TeensyNode received {"MOVE_TIME":575} from teensy
[teensy_node-3] [INFO] [1746579962.393244278] [teensy_node]: TeensyNode writing to teensy serial: {"MV": "WLK", "X": -124.0, "Y": 25.087, "Z": 0, "ROLL": 0.0, "PTCH": 0.0, "YAW": 0.0, "SPD": 261.56}
[teensy_node-3] [INFO] [1746579963.404000685] [teensy_node]: TeensyNode received {"MOVE_TIME":483} from teensy
[teensy_node-3] [INFO] [1746579963.593193791] [teensy_node]: TeensyNode writing to teensy serial: {"MV": "WLK", "X": -39.079, "Y": 6.806, "Z": 0, "ROLL": 0.0, "PTCH": 0.0, "YAW": 0.0, "SPD": 250}
```

seeing suspicious times reported occassionally

Closed 2025-06-23.

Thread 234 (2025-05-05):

fix new serial bug

DillonKane, 2025-05-05:
something is sending a bunch of empty commands, or causing the teensy to report receiving empty commands, even when log level  = 0

DillonKane, 2025-05-07:
https://github.com/ManufacturedMotion/Hexapod/pull/237

Closed 2025-05-07.

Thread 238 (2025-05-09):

Reinforce S3

Iacobacci, 2025-05-09:
Reinforce the S3 breaking points by increasing the amount of material around the S2 connector.

Closed 2025-05-21.

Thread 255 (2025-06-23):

New LED Mount

Iacobacci, 2025-06-23:
@zschwid Designed a new hexapod mount, @Iacobacci drop it into the current files and upload

Closed 2025-06-28.

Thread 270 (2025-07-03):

Test New Breakout PCBs

DillonKane, 2025-07-03:

DillonKane, 2025-07-17:
good to have but don't fix gobilda issues. 6x new breakouts will blow the 30A fuse, so only attach a limited number

Closed 2025-07-17.

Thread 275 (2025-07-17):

Increase Lid Screen Clearance

Iacobacci, 2025-07-17:
Currently the lid prevents access to the top and side of the screen, preventing scrolling from working. Increase the chamfer clearance around the screen.

Iacobacci, 2025-08-26:
Closing this out as it will be tackled in the full leg redesign.

Closed 2025-08-26.

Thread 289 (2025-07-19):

Add Protection Diodes

Iacobacci, 2025-07-19:
- Add protection diodes to the PCB to prevent back powering from moving the legs.
- Add protection diode to prevent back powering the board from a flipped battery connection

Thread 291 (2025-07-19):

Reduce Leg/Hexapod Printed Volume

Iacobacci, 2025-07-19:
The legs and Hexapod could be made lighter and allow for better airflow if the 3D prints were better optimized.

Iacobacci, 2025-09-01:
Closing as this will be covered with the leg redesign

Closed 2025-09-01.

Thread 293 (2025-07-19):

[CAD] Easily Replaceable Servos

Iacobacci, 2025-07-19:
Servos should be replaceable without needing to fully disassemble each leg.

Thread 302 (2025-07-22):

Servo Selection

Iacobacci, 2025-07-22:
The current servo choice results in servos either burning out or overheating.

Requirements:
- <$40 per servo ($720 for all 18 servos)
- Does not over hear (preferably metal body so we can increase air flow)
- >20KG minimum. Ideally in the 30KG range

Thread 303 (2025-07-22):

80mm Fan -> 2 40mm Fans

Iacobacci, 2025-07-22:
Modify the design to use two 40mm fans stacked horizontally, rather than one 80mm fan. The full 80mm height is not needed as we're currently blowing a lot of air at plastic, rather than focusing it on the pi.

This should result in more direct air flow, and free up space under the fan.

Closed 2025-08-12.

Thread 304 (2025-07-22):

Redesign S3

Iacobacci, 2025-07-22:
Redesign S3 with the following improvements:
- [ ] Add a Hall effect sensor w/magnet on the toe for position feedback.
- [ ] Increase the airflow around the servo.
- [ ] Better lock in the rod for the toe.
- [ ] Increase clearances so heat set inserts can be added without burning the plastic.

Iacobacci, 2025-08-26:
Closing this out as it will be tackled in the full leg redesign.

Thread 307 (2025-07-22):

Better support detaching servos

Iacobacci, 2025-07-22:
We added in support for detaching servos at OpenSauce 2025. However, not all bots will have servos that support this. To better account for that:

- [ ] Add a flag to user_config if the bot supports detaching.
- [ ] Add detach as a supported move in the queue.
- [ ] Trigger a detach every time a sit command is issued IFF the flag in user_config is set to true.

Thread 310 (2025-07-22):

Capacitors blowing fuse

Iacobacci, 2025-07-22:
Due to the inrush of current to fill up the capacitors, we are exceeding a peak current of 30A so we are blowing the main fuse. Currently, we can only add in the capacitors on 5/6 legs. This results in two different leg PCBs being needed to build the current design.

Potential solutions:
- Decrease the capacitor size per leg so all the boards are the same.
- Find a larger fuse block and confirm the board can support 35A.
- Add in transistors so we only power one leg at a time at startup.

Iacobacci, 2025-09-01:
This may be less of an issue with the switch to dc motors for S2/S3. Only S1 will be running a servo: https://github.com/ManufacturedMotion/Hex/issues/302

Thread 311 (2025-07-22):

S0 PCB Mounting

Iacobacci, 2025-07-22:
The mounting points on S0 for the PCB do not work, resulting in only one screw being used. Modify to allow the use of two screws, except on L5 where Velcro will be used instead.

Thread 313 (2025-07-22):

LED Ring Supports Right Joystick

Iacobacci, 2025-07-22:
Currently the LED ring has a mode where it will light up wherever the joystick is pointing. However, this doesn't work for the right joystick. The LED ring should light up whenever either joystick is moving, potentially having two different sets of light on at the same time

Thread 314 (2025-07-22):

Hex2 BOM Updates

Iacobacci, 2025-07-22:
The Hex2 BOM does not include:
- [ ] Springs and related parts
- [ ] GoBilda servo information

Add this information and validate current BOM is still accurate as we close out the Hex2 iteration.

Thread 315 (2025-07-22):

Hex2 CAD Updates

Iacobacci, 2025-07-22:
Clean up the assembly and publish with the following changes:

- [ ] The new springy leg
- [ ] The new(ish) version of S0

Closed 2025-08-12.

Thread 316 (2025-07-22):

S2 Pinches S3 Wire

Iacobacci, 2025-07-22:
The cross beam for S2 currently pinches the S3 wire, which resulted in it wearing down the cable sheathing around the servo wires.

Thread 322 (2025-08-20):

New s3

DillonKane, 2025-08-20:
- [x] new toe design that is more stable / does not fall out
- [x] s3 to use hall effect sensor for toe positioning

DillonKane, 2025-08-20:
new design mechanically working, just need to double check the sensor code.

also want to look into different ways of locking the sensor in place

Closed 2025-08-20.

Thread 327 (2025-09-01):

S3 CAD Revisions

Iacobacci, 2025-09-01:
- [ ] Embedded hall-effect sensor for toe position
- [ ] Better grip on hall-effect sensor
- [ ] Embedded axle coupling
- [ ] Change leg dimensions to fit within S2 redesign
- [ ] Servo -> Axle

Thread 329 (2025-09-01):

Leg PCB Redesign

Iacobacci, 2025-09-01:
- [ ] Support for 24v
- [ ] Compute on each leg
- [ ]

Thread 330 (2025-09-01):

Main PCB Redesign

Iacobacci, 2025-09-01:
- [ ] 24v -> 5v Buck Converter
- [ ] Additional pins for second fan
- [ ] Relays / Transistors for powering legs individually
- [ ] Protection Diodes (https://github.com/ManufacturedMotion/Hex/issues/289)

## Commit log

2025-08-12 update fan cad
2025-10-05 leg assembly
    [2025-10-05_leg-assembly.f3z]
2025-12-11 hex3 cad
    [2025-08-11_assembly.f3z, 2025-10-05_leg-assembly.f3z]
2025-12-15 CAD updatesbase
    [hexapod_mk2_main_v2.0.sch]
2025-12-16 S1->S2 connection bearing update
    [hexapod_mk2_main_v2.0.sch]
2025-12-22 increase S2 range of motion to +-90
    [Leg Assembly 2025-12-22.f3z]
2025-12-28 rename directories
    [Leg Assembly 2025-12-22.f3z]
2025-12-31 S3 updates
    [Leg Assembly 2025-12-31.f3z]
2026-01-11 S1, S2 finalized
    [Leg Assembly 2026-01-11.f3z]
2026-01-21 add s3
    [2026-01-20_leg-assembly.f3z]
2026-01-22 rename folder
    [2026-01-20_leg-assembly.f3z, HEX3_leg_board_v1.2.f3z, HEX3_leg_board_v1.2_top_bom.csv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]
2026-01-22 rename folder 2
    [2026-01-20_leg-assembly.f3z, HEX3_leg_board_v1.2.f3z, HEX3_leg_board_v1.2_top_bom.csv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]
2026-01-24 S1 updates
    [Leg Assembly 2026-01-18.f3z]
2026-01-26 add base assembly
2026-01-28 update leg cad with hardware
    [leg_assembly_2026-01-27.f3z]
2026-01-29 update CAD
    [2026-01-20_leg-assembly.f3z, 2026-01-28_leg-assembly.f3z, Leg Assembly 2025-12-22.f3z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]
2026-02-02 update CAD:
2026-03-23 CAD Updates
2026-03-28 S1 printability
2026-04-04 pi mounting ease
2026-04-05 encoder assembly tools
    [encoder_assembly_tools.f3z]
2026-04-11 S1 encoder cover tweaks
    [encoder_assembly_tools.f3z]
2026-05-17 magnet modularity
2026-05-30 v2 leg board
    [HEX3_leg_board_v2.0 v69_top_bom.csv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]
2026-06-05 minor CAD improvements
2026-06-22 add wire lengths:
2026-06-23 Cad Improvements
2026-07-07 wire management
2026-07-14 leg calibration docs
2026-07-17 add Raspberry Pi Setup Docs
2026-07-29 3D printing guide
2026-08-03 v3.2 PCB files
    [HEX3_leg_board_PCB_v3.2 top_bom-JLCPCB Assembly Order.xls, HEX3_leg_board_PCB_v3.2 top_bom.csv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]
2026-08-03 update pcb subfolders
    [HEX3_leg_board_PCB_v3.2 top_bom-JLCPCB Assembly Order.xls, HEX3_leg_board_PCB_v3.2 top_bom.csv, HEX3_leg_board_v2.0 v69_top_bom.csv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]
2026-08-03 add main pcb files
2026-08-03 move main pcb files
    [HEX3_leg_board_PCB_v3.2 top_bom-JLCPCB Assembly Order.xls]
2026-08-03 add PCB readme
2026-08-03 Clarify leg board specifications and features
    Updated README.md to clarify board specifications and features.
2026-08-03 Fix BOM and CPL file path in README
    Updated the path for BOM and CPL files in the README.
2026-08-15 add pcb reference pictures
2026-08-15 crop pcb pictures
2026-08-15 Update pcb-assembly.md
    add pictures to pcb assembly readme
2026-09-02 Fix typo in 3D printing documentation
2026-09-02 Update PCB assembly instructions for clarity
    Clarified assembly instructions for V3.2 and V2.0 boards, including diode and capacitor placements.
2026-09-02 Document motor wiring and PCB connection details
    Added guidelines for motor wiring polarity and leg PCB connections.
2026-09-02 add 3mfs
    [base_core.3mf, base_electronics_mount.3mf, base_flat_x12.3mf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]
2026-09-02 add step files
    [encoder_assembly_tools_2026_05_16.f3z, encoder_insertion_tool.f3d, encoder_insertion_tool.step]
2026-09-02 Update mechanical assembly instructions with additional notes
    Added a note about applying Blue Loctite to the grub screw and included a reminder about the experimental status of the toe distance time-of-flight sensor.
2026-09-05 Document Leg PCB versions and their differences
    Added details about Leg PCB versions V2.0 and V3.2, including assembly methods, thermal management, and pros and cons for each version.
2026-09-07 Revise Hex3 details and add Printables link
    Updated Hex3 release information and added links to project resources.
